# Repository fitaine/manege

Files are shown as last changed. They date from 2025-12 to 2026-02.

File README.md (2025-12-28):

# Manège 🎠
## A Simple 360° Photo Turntable for Documenting Your Work

<p align="center">
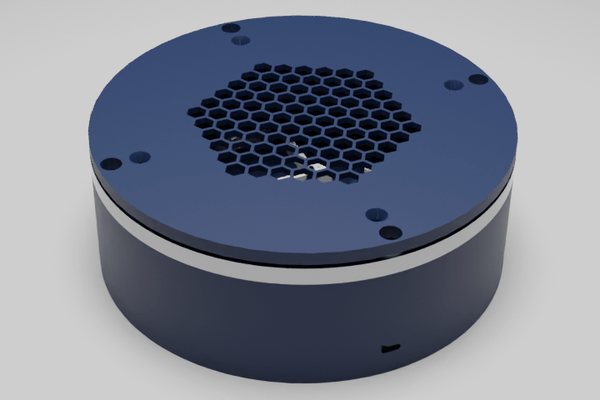
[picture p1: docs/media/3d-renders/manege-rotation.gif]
Manège Turntable Animation
  
</p>

I built this for my wife, who makes willow baskets. She needed a way to document everything she creates - to showcase her work to potential clients, remember past pieces, and build up a portfolio over time. Turns out photographing dozens of baskets gets tedious fast, so I made this automated turntable that uploads photos directly to her website.

It ain't much, but it's honest work. Maybe it'll be useful for your workshop too.

---

## What It Does

- Rotates objects on a turntable and takes photos automatically
- Uploads pictures to WordPress as you shoot (so your website stays updated)
- Has a simple web interface you can use from your phone
- Powers everything through a single Ethernet cable (PoE)
- Includes LED lighting control if you need consistent lighting

It's basically a lazy susan with a stepper motor, a Raspberry Pi with cameras, and some code to tie it together.

---

## Why I Built It This Way

### The Story
When you make things by hand - baskets, pottery, woodwork, whatever - you end up with a lot of items that need photographing. Setting up each shot, rotating the object, taking multiple angles... it's repetitive and takes time away from actual making.

My wife needed:
- A record of everything she's made (memory fades, photos don't)
- Images to show potential clients ("I can make something like this one")
- A way to keep her website gallery updated without the hassle

### The Solution
Instead of a fancy commercial product photography rig, I went with parts you can actually get:
- **Raspberry Pi 5** - Does the heavy lifting (cameras, web server, uploads)
- **ESP32** - Controls the turntable motor
- **PoE HAT** - Powers everything through the Ethernet cable (one less wire to worry about)
- **Lazy susan bearing** - The turntable base (8 inches, supports decent-sized objects)
- **Stepper motor** - Smooth, precise rotation

It's all open source hardware and software. Build it yourself, modify it, whatever works for you.

---

## What You Get

### Camera System
- Two Raspberry Pi cameras (one for preview, one for high-res shots)
- Manual controls for focus, exposure, white balance
- Live preview so you can see what you're shooting
- 360° sequences with however many photos you want

### Turntable
- 8-inch diameter (handles most hand-made objects)
- Precise rotation steps (can go as fine as 0.005625° per step)
- Controlled over WiFi from the web interface

### Web Interface
- Works on phones, tablets, computers - anything with a browser
- Simple controls: rotate, capture, adjust settings
- Live camera preview
- No app to install
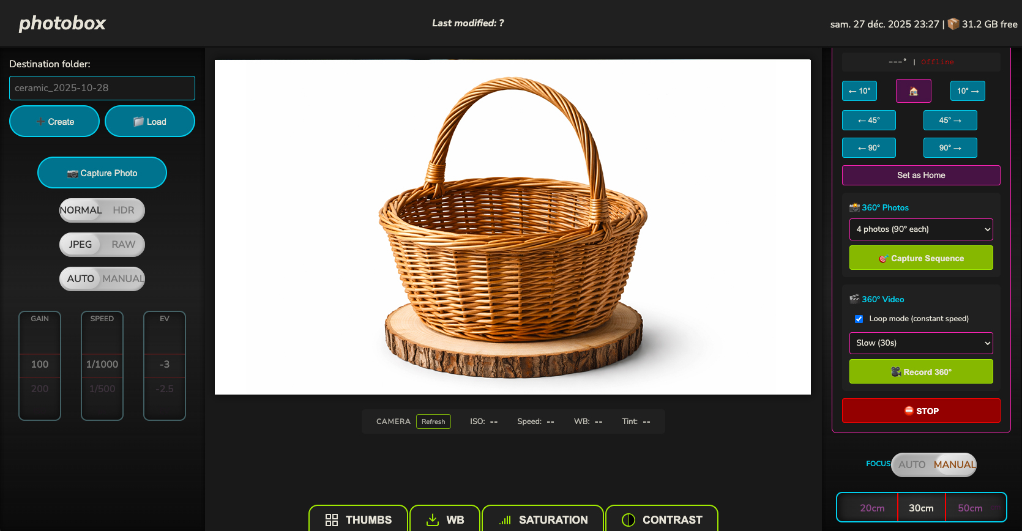
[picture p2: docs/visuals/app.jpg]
Manège Web Interface
<p align="center">    <br>  <em>The Manège web interface - live preview, camera controls, and automated 360° capture</em></p>

### WordPress Integration
- Photos upload automatically to your WordPress site
- Builds a gallery as you shoot
- Tag and organize as you go
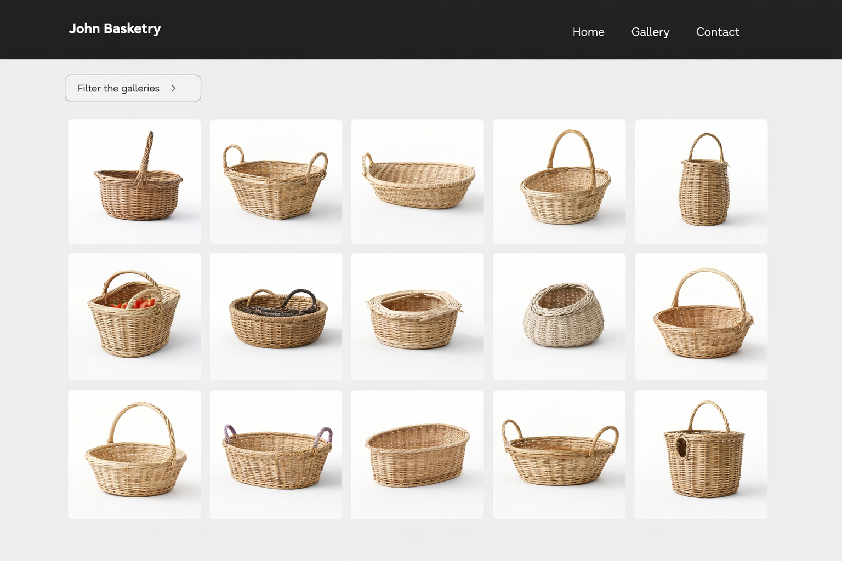
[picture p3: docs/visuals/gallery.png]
WordPress Gallery Grid
<p align="center">    <br>  <em>Example WordPress gallery showing organized product catalogue - clean grid layout for easy browsing</em></p>

### LED Control
- If you add LED strips for lighting, the system can control them
- Brightness adjustment via PWM
- All powered from the same PoE supply

---

## What You Need to Build One

### Core Parts
- Raspberry Pi 5 (8GB or 16GB)
- Raspberry Pi Camera Module 3
- Raspberry Pi HQ Camera
- PoE+ HAT for Raspberry Pi 5
- ESP32 dev board
- NEMA 17 stepper motor
- DRV8825 stepper driver
- 8-inch lazy susan bearing
- Power components (buck converters, etc.)

### Optional Additions
- LED light strips (12V COB strips work well)
- Enclosure (3D printable files included)
- MOSFET for LED control

**Full parts list with links: [BOM.md](BOM.md)**

The total cost is reasonable for what you get - cheaper than commercial photo turntables with fewer features.

---

## Getting Started

### Build the Hardware
Follow [ASSEMBLY_ORDER.md](ASSEMBLY_ORDER.md) for step-by-step instructions. The electrical wiring guide is in `hardware/electrical/wiring-guide.md`.

### Set Up the Software
```bash
cd manege
cp config.example.py config.py
nano config.py  # Add your WiFi and WordPress details
pip3 install -r requirements.txt
```

### Flash the ESP32
The turntable controller firmware is in `firmware/esp32_turntable/`. Upload it with Arduino IDE or PlatformIO.

### Start It Up
```bash
./scripts/start_webapp.sh
```

Then open `http://<raspberry-pi-ip>:5000` in your browser.

---

## How It Works

1. **Power On**: Plug in one PoE Ethernet cable. That's it - the Pi, cameras, LEDs, and turntable all power up.
2. **Take Photos**: Use the web interface to position your object, adjust camera settings, and capture.
3. **Auto-Upload**: Photos go straight to your WordPress media library and gallery.
4. **Keep Going**: Document your next piece. The system's ready whenever you are.

It's designed to be something you can use daily without thinking about it.

---

## Real Use Case: Willow Baskets

My wife makes traditional willow baskets. Each one is unique - different sizes, shapes, weaving patterns. Over a year, that's 50-100+ baskets.

Before Manège:
- Set up phone or camera on a tripod
- Manually rotate basket
- Take 8-12 photos per basket
- Transfer photos to computer
- Resize, rename, upload to website
- Repeat for next basket

With Manège:
- Place basket on turntable
- Press "Capture 360°"
- Watch it rotate and shoot automatically
- Photos appear in website gallery
- Done

The time savings add up fast. More importantly, she actually uses it - which means her website stays updated and potential clients can see what she's capable of making.

---

## Can You Use This?

If you make physical things and need photos of them, probably yes:
- Pottery, ceramics
- Woodworking, furniture
- Metalwork, jewelry
- Leather goods
- Textiles, baskets
- Scale models, miniatures
- Product prototypes

If you're just getting started and don't have many items yet, you might not need the automation. But if you're making dozens or hundreds of pieces a year, this saves real time.

---

## Documentation

- [Bill of Materials](BOM.md) - Parts list with supplier links
- [Assembly Guide](ASSEMBLY_ORDER.md) - How to build it
- [Wiring Guide](hardware/electrical/wiring-guide.md) - Electrical connections
- [Camera Setup](app/CAMERA_SETUP.md) - Configuring the Raspberry Pi cameras
- [Git Guide](GIT_QUICK_GUIDE.md) - How to contribute

---

## Contributing

This is an open project. If you build one and make improvements, share them:
- Better enclosure designs
- Code improvements
- Documentation fixes
- Ideas for features

[GitHub Issues](https://github.com/fitaine/manege/issues) is the place for bug reports and feature requests.

---

## License

- **Software**: MIT License - Use it however you want
- **Hardware**: CERN-OHL-P-2.0 - Open source hardware

Build it, sell products photographed with it, modify it for your needs. That's what open source is for.

---

## Credits

This project started with [twirly](https://github.com/veebch/twirly) by veebch - an elegant ESP32-based turntable. I added the Raspberry Pi cameras, PoE power system, LED control, WordPress integration, and web interface to make it work for documenting craft work at scale.

Thanks to veebch for the foundation and for open-sourcing their design.

---

## Support

Built in the Jura mountains of France, one piece at a time.

- **Website**: [tiphainebuccino.com](https://tiphainebuccino.com)
- **Issues**: [GitHub Issues](https://github.com/fitaine/manege/issues)

---

*Made for makers who'd rather spend time making things than photographing them.*

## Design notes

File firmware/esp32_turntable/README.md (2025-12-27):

# ESP32 Turntable Firmware

ESP32-based stepper motor controller for precision turntable rotation.

## Origins

The turntable control concept is inspired by [twirly](https://github.com/veebch/twirly) by veebch.

Manège extends this with:
- Enhanced precision (1/32 microstepping, 64,000 steps/360°)
- Multiple speed profiles for photography modes
- Loop-ready video mode
- Integration with Raspberry Pi camera

## Features

- Precision: 0.005625° per step (64,000 steps/360°)
- Microstepping: 1/32 for smooth motion
- HTTP API for WiFi control
- Multiple speed profiles (SLOW, MEDIUM, FAST, VIDEO)

## Configuration

1. Copy config.example.h to config.h
2. Edit with your WiFi credentials
3. Upload to ESP32 via Arduino IDE

## HTTP API Endpoints

- GET /status - Current position and state
- POST /left?degrees=N - Rotate left
- POST /right?degrees=N - Rotate right
- POST /home - Return to home position
- POST /photo360?count=N - Photo sequence mode
- POST /video360?duration=N - Video recording mode

## Hardware

- ESP32 DevKit
- NEMA 17 stepper motor
- DRV8825 driver
- 10:1 gear ratio

See hardware/ directory for complete documentation.

## Acknowledgments

Inspired by [twirly](https://github.com/veebch/twirly) by veebch.

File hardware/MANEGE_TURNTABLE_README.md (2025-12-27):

# Manège Turntable Project - Complete System Documentation

**Last Updated: November 28, 2025**
**Status: ✅ FULLY OPERATIONAL - Advanced Features Implemented**

---

## Table of Contents
1. [Overview](#overview)
2. [Current System Status](#current-system-status)
3. [What We've Achieved](#what-weve-achieved)
4. [System Architecture](#system-architecture)
5. [Features](#features)
6. [Hardware Configuration](#hardware-configuration)
7. [Software Components](#software-components)
8. [UI Layout](#ui-layout)
9. [Next Steps & TODO](#next-steps--todo)
10. [File Locations](#file-locations)
11. [Known Issues](#known-issues)

---

## Overview

Your manege is a complete automated photography system for capturing basketry and craft objects with:
- **Raspberry Pi Camera Module V3** (NoIR - No Infrared filter)
- **ESP32-controlled motorized turntable** with DRV8825 stepper driver
- **Web-based interface** for full remote control
- **Flask backend** (Python) serving camera and turntable APIs
- **Advanced camera controls**: Manual focus, exposure, WB, saturation, contrast
- **360° automation**: Photo sequences and video recording with loop mode

---

## Current System Status

### ✅ Working Features
- Live camera preview (MJPEG stream)
- Manual camera controls (focus, ISO, shutter, WB, saturation, contrast)
- HDR photo capture with EV compensation
- 360° photo sequences (4, 8, 12, 18 photos)
- 360° video recording with loop mode (constant-speed, loopable videos)
- Turntable manual control (left/right, home, set home)
- Emergency stop functionality
- Photo thumbnails with subfolder support
- Bottom panel UI (thumbnails, WB, saturation, contrast) - collapsed by default
- Focus: Horizontal carousel, manual mode by default (30cm)

### ⚠️ Needs Attention
- **ESP32 firmware upload required** for latest loop mode features
- Some UI elements may need final testing after recent changes

### 🔧 Configuration Details
- **Camera**: Raspberry Pi Camera Module V3 NoIR
- **Resolution**: 1920×1080 for video, configurable for photos
- **Network**:
  - Flask app: <PI_IP_ADDRESS>:5000
  - ESP32 turntable: <ESP32_IP_ADDRESS> (update if needed)
- **Photo storage**: `/home/yourusername/Pictures/` with date-organized folders

---

## What We've Achieved

### Session 1 (Nov 27, 2025) - Initial Integration
✅ ESP32 firmware created with HTTP API
✅ Flask backend turntable endpoints
✅ Web UI integrated into right panel
✅ Manual rotation controls working
✅ 360° photo sequences functional
✅ 360° video recording implemented

### Session 2 (Nov 28, 2025) - Advanced Features & Refinements

#### Camera & Capture Improvements
✅ Fixed camera blocking issues (pkill rpicam-vid before sequences)
✅ Added overlay messages during 360° capture/video
✅ Removed confirmation popups for smoother workflow
✅ Manual focus/exposure now applied in sequences
✅ Fixed EV settings conflict with HDR mode
✅ Enhanced emergency stop (kills processes, resets UI, restarts feed)
✅ Updated photo count options (4, 8, 12, 18 photos - removed 24+)
✅ Fixed thumbnails to show photos from sequence subfolders

#### ESP32 Firmware Enhancements
✅ Implemented 1/32 microstepping for smoother motion
✅ Gentle accelerations (300-500 steps/sec²) for basketry safety
✅ Return-to-home now uses shortest path (CW vs CCW)
✅ Dynamic speed calculation based on duration
✅ Proportional acceleration (reaches full speed in 10% of duration)
✅ **Loop mode implementation**:
  - Pre-positions backwards 10% (36°)
  - Accelerates through starting position to reach cruise speed
  - Records only constant-speed portion (80% of duration)
  - Decelerates after recording
  - Returns to exact starting position

#### Video Recording Features
✅ Loop mode checkbox (enabled by default)
✅ Speed presets: Fast (10s), Medium (20s), Slow (30s), Very Slow (45s), Ultra Slow (60s)
✅ Loop mode produces seamless, loopable videos
✅ Full rotation mode option (records acceleration/deceleration)
✅ Turntable returns to home position after loop mode video

#### UI Improvements
✅ Focus carousel made horizontal (saves ~130px vertical space)
✅ Focus carousel height reduced to 50px
✅ "FOCUS" label moved above auto/manual toggle
✅ Focus defaults to Manual mode with 30cm setting
✅ Focus carousel scrolls to 30cm position on load
✅ Bottom panel (thumbnails/WB/saturation/contrast) collapsed by default
✅ Removed redundant video controls

---

## System Architecture

```
┌─────────────────────────────────────────────────┐
│  Web Browser (Client)                           │
│  - HTML/CSS/JavaScript UI                       │
│  - Displays live camera feed                    │
│  - Controls camera & turntable                  │
└──────────────────┬──────────────────────────────┘
                   │ HTTP
                   ↓
┌─────────────────────────────────────────────────┐
│  Raspberry Pi (<PI_IP_ADDRESS>:5000)                │
│  ┌───────────────────────────────────────────┐  │
│  │ Flask App (Python)                        │  │
│  │ - Serves web UI                           │  │
│  │ - Controls camera (rpicam-vid/still)      │  │
│  │ - Proxies turntable commands              │  │
│  │ - Manages photo storage                   │  │
│  └───────────────────┬───────────────────────┘  │
│                      │                           │
│  ┌───────────────────┴───────────────────────┐  │
│  │ Camera Module V3 NoIR                     │  │
│  │ - Live preview stream                     │  │
│  │ - Photo capture (JPEG/RAW/DNG)            │  │
│  │ - Video recording (H264→MP4)              │  │
│  └───────────────────────────────────────────┘  │
└──────────────────┬──────────────────────────────┘
                   │ HTTP
                   ↓
┌─────────────────────────────────────────────────┐
│  ESP32 (<ESP32_IP_ADDRESS>)                           │
│  ┌───────────────────────────────────────────┐  │
│  │ HTTP Server (C++)                         │  │
│  │ - AccelStepper control                    │  │
│  │ - Position tracking                       │  │
│  │ - Loop mode logic                         │  │
│  └───────────────────┬───────────────────────┘  │
│                      │                           │
│  ┌───────────────────┴───────────────────────┐  │
│  │ DRV8825 Stepper Driver                    │  │
│  │ - 1/32 microstepping                      │  │
│  │ - NEMA stepper motor control              │  │
│  │ - 6400 steps/revolution                   │  │
│  └───────────────────┬───────────────────────┘  │
│                      │                           │
│  ┌───────────────────┴───────────────────────┐  │
│  │ NEMA Stepper Motor                        │  │
│  │ - Turntable rotation                      │  │
│  │ - 200 steps/rev (×32 microstepping)       │  │
│  └───────────────────────────────────────────┘  │
└─────────────────────────────────────────────────┘
```

---

## Features

### Camera Controls

#### Focus
- **Auto/Manual toggle**
- **Manual settings**: Infinity, 2m, 1m, 60cm, **30cm (default)**, 20cm, 15cm, 10cm
- **Horizontal carousel** interface (50px height)
- Position saved and applied to all captures

#### Exposure
- **Auto/Manual modes**
- **Manual controls**:
  - ISO: 100-800
  - Shutter: 1/8000 to 1 second
  - EV Compensation: -2 to +2 (HDR mode only)
- Settings preserved across sequences

#### White Balance
- **Presets**: Auto, Daylight, Cloudy, Shade, Tungsten, Fluorescent, Flash, Custom
- **Custom RGB tuning**: Fine-tune red/blue gains
- Applied to all photos and videos

#### Image Adjustments
- **Saturation**: -100 to +100
- **Contrast**: -100 to +100
- Real-time preview on live feed

### Photo Capture

#### Single Photo
- JPEG, RAW (DNG), or Both formats
- HDR mode with 3-bracket exposure
- Current settings applied (focus, WB, etc.)

#### 360° Photo Sequence
- **Photo counts**: 4, 8, 12, or 18 photos
- **Default**: 4 photos (90° spacing)
- Auto-rotation between shots
- Saved to timestamped subfolder (`360seq_YYYYMMDD_HHMMSS/`)
- Returns to home position when complete
- Thumbnails show in bottom panel

### Video Recording

#### 360° Video with Loop Mode
**Loop Mode (default, checkbox enabled):**
- Pre-positions backwards 36° before starting
- Accelerates to cruise speed while returning to start position
- Records only constant-speed rotation (no acceleration in video)
- Creates seamless, loopable videos perfect for web
- Returns to starting position after recording

**Speed Presets:**
- Fast (10s): ~8s of usable footage
- Medium (20s): ~16s of usable footage
- Slow (30s): ~24s of usable footage
- Very Slow (45s): ~36s of usable footage
- Ultra Slow (60s): ~48s of usable footage

**Full Rotation Mode (checkbox unchecked):**
- Records entire rotation including acceleration/deceleration
- Good for documentary-style captures

**Output**: MP4 format (H264 encoding, 1920×1080, 30fps)

### Turntable Controls

#### Manual Control
- **Left/Right**: Rotate in 10°, 45°, or 90° increments
- **Home**: Return to reference position (0°)
- **Set as Home**: Mark current position as starting point
- **Emergency Stop**: Immediate halt with full system reset

#### Automation
- 360° photo sequences (integrated with camera settings)
- 360° video recording with loop mode
- Smooth acceleration/deceleration for delicate objects
- Position tracking and return-to-home

### Safety Features
- Emergency stop kills all processes (camera + turntable)
- Gentle accelerations protect basketry and motor
- 1/32 microstepping eliminates vibration
- Shortest-path homing reduces wear
- Clear status indicators and overlay messages

---

## Hardware Configuration

### Raspberry Pi Camera
- **Model**: Raspberry Pi Camera Module V3 NoIR
- **Resolution**: 1920×1080 (video), higher for stills
- **Connection**: CSI ribbon cable (blue side facing USB ports)

### ESP32 Turntable
```
ESP32 Pins → DRV8825:
  STEP: GPIO 5
  DIR:  GPIO 2
  SLP:  GPIO 18
  RST:  GPIO 23
  EN:   GPIO 15
  M0:   GPIO 4  (HIGH for 1/32 microstepping)
  M1:   GPIO 22 (HIGH for 1/32 microstepping)
  M2:   GPIO 19 (HIGH for 1/32 microstepping)

Network:
  WiFi SSID: YourWiFiName
  Password: YourWiFiPassword
  Static IP: <ESP32_IP_ADDRESS>

Motor Configuration:
  Steps per revolution: 200 (NEMA 17)
  Microstepping: 1/32
  Total steps: 6400 per revolution
```

### Speed & Acceleration Settings
```cpp
// Speeds (steps per second)
SPEED_SLOW = 800      // Photo capture (very smooth)
SPEED_MEDIUM = 1200   // General positioning
SPEED_FAST = 1600     // Return home
SPEED_VIDEO = 400     // Ultra slow for video

// Accelerations (steps per second²)
ACCEL_SLOW = 300      // Very gentle start/stop
ACCEL_MEDIUM = 400    // Gentle acceleration
ACCEL_FAST = 500      // Return home (still gentle)

// Video mode uses dynamic calculation:
// accel = speed / (duration × 0.1)
// Reaches full speed in 10% of rotation time
```

---

## Software Components

### Backend: Flask App (`/home/yourusername/Documents/app.py`)

**Key Functions:**
- `video_feed()` - MJPEG live stream
- `capture_photo()` - Single photo with settings
- `capture_360_sequence()` - Automated photo sequence
- `record_360_video()` - 360° video with loop mode
- `kill_camera_processes()` - Emergency camera reset
- Turntable proxy endpoints (status, left, right, home, etc.)

**Recent Changes:**
- Added loop mode support with pre-positioning
- Dynamic video duration calculation (80% of total for loop mode)
- Return-to-home after loop mode videos
- Subfolder scanning for thumbnails
- Fixed HDR/manual exposure conflicts

### Frontend: Web UI (`/home/yourusername/Documents/templates/index.html`)

**Structure:**
- **Left Panel**: Live preview, capture overlay, photo modal
- **Right Panel**: Camera controls, turntable controls
- **Bottom Panel**: Thumbnails, WB tuning, Saturation, Contrast (collapsed by default)

**Key JavaScript Functions:**
- `capture360Sequence()` - Photo sequence with overlay
- `record360Video()` - Video recording with countdown
- `emergencyStop()` - Full system abort
- `createCarousel()` - Dynamic control carousels
- `updateLiveFocus()`, `updateLiveExposure()` - Real-time settings

### Firmware: ESP32 (`/home/yourusername/Documents/scripts/esp32_turntable/esp32_turntable.ino`)

**HTTP Endpoints:**
- `/status` - Get position and state
- `/left`, `/right` - Manual rotation
- `/rotate_degrees` - Rotate by specific amount
- `/home` - Return to home (shortest path)
- `/set_home` - Set current as home position
- `/photo360` - Photo sequence mode
- `/video360` - Normal video mode
- `/video360_loop` - **New: Loop mode with pre-positioning**
- `/stop` - Emergency stop

**Key Functions:**
- `handleVideo360Loop()` - **New: Pre-position, accelerate, cruise rotation**
- `handleHome()` - Shortest path calculation
- `rotateByDegrees()` - Smooth rotation with accel/decel
- `runToTarget()` - Blocking movement execution

---

## UI Layout

### Right Panel (Top to Bottom)

1. **Photo Format** (JPEG/RAW/Both dropdown)
2. **Capture Photo** button
3. **HDR Mode** toggle + EV slider
4. **Exposure Control** (Auto/Manual toggle + ISO/Shutter carousels)
5. **360° Photo Sequence** (count selector + Capture button)
6. **Turntable Manual Controls** (Left/Right buttons, Home, Set Home)
7. **360° Video** (Loop mode checkbox + speed selector + Record button)
8. **Emergency Stop** button (red)
9. **Focus Control** ("FOCUS" title + Auto/Manual toggle + horizontal carousel)

### Bottom Panel (Tabs - Collapsed by Default)

- **Thumbnails**: Recent photos with subfolder support
- **White Balance**: Preset selector + custom RGB tuning
- **Saturation**: Slider (-100 to +100)
- **Contrast**: Slider (-100 to +100)

---

## Next Steps & TODO

### 🔴 Critical - Must Do
1. **Upload updated ESP32 firmware** to enable:
   - Loop mode pre-positioning
   - 1/32 microstepping
   - Shortest-path homing
   - Dynamic acceleration

2. **Test loop mode video** after firmware upload:
   - Verify pre-positioning works
   - Check if object returns to exact start position
   - Confirm video has constant speed (no acceleration visible)

### 🟡 Important - Should Do
3. **Calibrate turntable speeds** for your specific setup:
   - Test different video presets (10s, 20s, 30s)
   - Adjust if rotation too fast/slow for your objects
   - Fine-tune acceleration times if needed

4. **Document your workflow**:
   - Best settings for different basket types
   - Lighting setup notes
   - Object placement guidelines

5. **Backup configuration**:
   ```bash
   cp /home/yourusername/Documents/app.py /home/yourusername/Documents/app.py.backup
   cp /home/yourusername/Documents/scripts/esp32_turntable/esp32_turntable.ino /home/yourusername/Documents/scripts/esp32_turntable/esp32_turntable.ino.backup
   ```

### 🟢 Nice to Have - Future Enhancements
6. **Video post-processing**:
   - Auto-trim to exact 360° rotation
   - Color grading pipeline
   - Batch processing scripts

7. **Additional camera features**:
   - Bracketed focus stacking
   - Timelapse mode with rotation
   - Multi-row captures (vertical adjustment)

8. **UI improvements**:
   - Save/load preset configurations
   - Quick access to recent settings
   - Keyboard shortcuts

9. **Hardware upgrades**:
   - Limit switches for precision homing
   - Position encoder for closed-loop control
   - LED ring light integration
   - Vertical axis control for 3D scanning

10. **Export features**:
    - Photogrammetry mesh generation
    - Automatic background removal
    - 360° viewer web embed code

---

## File Locations

### Core Files
```
Flask Backend:
  /home/yourusername/Documents/app.py

Web UI:
  /home/yourusername/Documents/templates/index.html

ESP32 Firmware:
  /home/yourusername/Documents/scripts/esp32_turntable/esp32_turntable.ino

Photo Storage:
  /home/yourusername/Pictures/YYYY-MM-DD/
  /home/yourusername/Pictures/YYYY-MM-DD/360seq_YYYYMMDD_HHMMSS/

Current Folder Tracker:
  /home/yourusername/Pictures/current_folder.txt
```

### Documentation
```
Main README:
  /home/yourusername/Documents/MANEGE_TURNTABLE_README.md (this file)

Setup Guide:
  /home/yourusername/Documents/TURNTABLE_SETUP.md

TODO List:
  /home/yourusername/Documents/TODO.md (to be created)

Session Notes:
  See conversation history for detailed implementation notes
```

### Scripts
```
Flask Startup:
  /home/yourusername/Documents/scripts/start_webapp.sh
  /home/yourusername/Documents/scripts/run_manege.sh
```

---

## Known Issues

### Camera Feed Occasionally Disappears
**Symptom**: Live preview stops loading
**Cause**: rpicam-vid process dies or gets stuck
**Solution**: Emergency stop button kills and restarts camera processes
**Prevention**: Current implementation includes automatic cleanup before sequences

### Thumbnails Don't Update Immediately
**Symptom**: New photos don't appear in thumbnail panel right away
**Cause**: Thumbnail refresh was removed to prevent scope errors
**Workaround**: Click on thumbnail tab to manually refresh
**Future Fix**: Implement proper scoped refresh function

### Focus Carousel Position on Page Load
**Status**: ✅ FIXED - Now scrolls to 30cm on initialization
**Implementation**: Searches for `.selected` item and scrolls to it

### Loop Mode Timing
**Status**: ⚠️ NEEDS TESTING after firmware upload
**Note**: Pre-positioning and acceleration times are estimates
**Potential Issue**: Object might not be exactly at start position when recording begins
**Solution**: Fine-tune timing constants in app.py:
```python
accel_time = duration * 0.1  # Adjust if needed
preposition_time = 2.0       # Adjust if needed
```

---

## Troubleshooting Quick Reference

| Problem | Solution |
|---|---|
| Camera not detected | Check ribbon cable, run `vcgencmd get_camera` |
| Live feed not loading | Emergency Stop, wait 2s, refresh page |
| Turntable shows "Offline" | Check ESP32 power, WiFi, verify IP <ESP32_IP_ADDRESS> |
| Motor not moving | Verify wiring, check VMOT voltage, test with `/status` |
| Jerky rotation | Upload latest firmware with 1/32 microstepping |
| Photos not in thumbnails | Click thumbnails tab, check `/home/yourusername/Pictures/` |
| Video too fast/slow | Change speed preset or adjust firmware constants |
| Loop mode not working | Upload latest ESP32 firmware with `handleVideo360Loop()` |
| Object not at start after loop | Adjust `preposition_time` in app.py |

---

## Useful Commands

### Camera
```bash
# Check camera detection
vcgencmd get_camera

# List camera processes
ps aux | grep rpicam

# Kill all camera processes
sudo pkill -9 -f rpicam

# Test camera capture
rpicam-still -o test.jpg
```

### Flask App
```bash
# Check if Flask is running
pgrep -f "flask run"

# View Flask logs
tail -f /tmp/flask.log

# Restart Flask (if using systemd)
sudo systemctl restart manege
```

### ESP32
```bash
# Test ESP32 connectivity
curl http://<ESP32_IP_ADDRESS>/status

# Test rotation
curl -X POST http://<ESP32_IP_ADDRESS>/preset/45
```

### Photos
```bash
# List recent photos
ls -lth /home/yourusername/Pictures/2025-11-28/ | head

# Count photos in sequences
find /home/yourusername/Pictures/ -name "360seq_*" -type d | wc -l

# Check disk space
df -h /home/yourusername/Pictures/
```

---

## Credits & Licenses

**Project**: Custom manege for basketry documentation
**Hardware**: Raspberry Pi, ESP32, DRV8825, NEMA stepper, Camera Module V3
**Software Stack**: Flask, rpicam-apps, AccelStepper, ArduinoJson

**Libraries Used:**
- Flask (Pallets Projects) - BSD License
- AccelStepper (Mike McCauley) - GPL
- ArduinoJson (Benoit Blanchon) - MIT License
- rpicam-apps (Raspberry Pi Foundation) - BSD License

---

## Support & Maintenance

### Regular Maintenance
- Clean camera lens monthly
- Check motor temperature after long sequences
- Tighten wire connections if vibration occurs
- Keep firmware and app.py backed up
- Test emergency stop periodically

### Getting Help
- Review this document first
- Check TURNTABLE_SETUP.md for detailed guides
- Check conversation history for implementation details
- Test individual components in isolation

---

**Ready to capture professional 360° basketry photos and videos!** 📷🔄✨

**Next step**: Upload the updated ESP32 firmware to enable loop mode!

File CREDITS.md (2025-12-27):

# Credits & Attribution

## Original Inspiration

**Manège** began as a development of the [twirly](https://github.com/veebch/twirly) project by [veebch](https://github.com/veebch).

### twirly - Original Project
- **Repository:** https://github.com/veebch/twirly
- **Author:** veebch
- **Concept:** ESP32-controlled turntable for product photography
- **License:** MIT License

### What We Borrowed from twirly
- ESP32 + stepper motor architecture
- Basic HTTP API concept for turntable control
- Inspiration for 360° rotation automation
- DRV8825 stepper driver approach

### What Manège Adds
Manège evolved twirly into a **complete photography solution** for artisans and craftspeople:

**Camera System:**
- Raspberry Pi Camera Module V3 integration
- Live MJPEG preview stream
- Manual focus control with preset positions
- Manual exposure (ISO + shutter speed)
- White balance sampling and adjustment
- HDR capture mode (3-exposure bracketing)
- RAW + JPEG capture options

**Software:**
- Flask-based web interface
- 360° photo sequencing automation
- 360° video recording with loop mode
- Photo management and storage
- Real-time camera preview with controls

**Hardware Enhancements:**
- Higher precision: 64,000 steps/360° (vs standard resolution)
- 1/32 microstepping for smooth motion
- Multiple speed profiles (photo, video, positioning)
- Network configuration system
- Professional wiring and power design

**Target Audience:**
- Professional and semi-professional photographers
- Artisans creating product catalogs
- Small businesses needing product photography
- Craftspeople (basketry, pottery, etc.)

## Development Philosophy

While inspired by twirly's elegant simplicity, Manège is a **separate development** aimed at a different use case:

- **twirly:** Minimalist turntable for basic 360° capture
- **Manège:** Complete photography system with professional features

This is not a fork in the technical sense, but rather a parallel development that took the core turntable concept and built a comprehensive solution around it.

## License Compatibility

Both projects use permissive open-source licenses:
- **twirly:** MIT License
- **Manège:** MIT License (software) + CERN-OHL-P-2.0 (hardware)

## Thank You

Special thanks to **veebch** for creating twirly and sharing it with the open-source community. Your project provided the perfect starting point for this development! 🙏

If you're looking for a **simple, minimalist turntable**, check out the original [twirly](https://github.com/veebch/twirly).

If you need a **complete photography system** with camera integration and advanced features, that's what Manège offers.

---

## Other Acknowledgments

### Software & Libraries
- **Flask** - Web framework (BSD License)
- **Pillow** - Image processing (HPND License)
- **libcamera** - Raspberry Pi camera interface
- **ArduinoJson** - JSON parsing for ESP32
- **AccelStepper** - Stepper motor control library

### Hardware
- **Raspberry Pi Foundation** - Pi and Camera Module
- **Espressif** - ESP32 platform
- **Community designs** - DRV8825 driver circuits

### Inspiration
- Artisan basketry photography workflows
- Professional product photography techniques
- Open-source hardware movement

---

**Manège** stands on the shoulders of giants. Thank you to everyone who contributes to open-source! 🎉

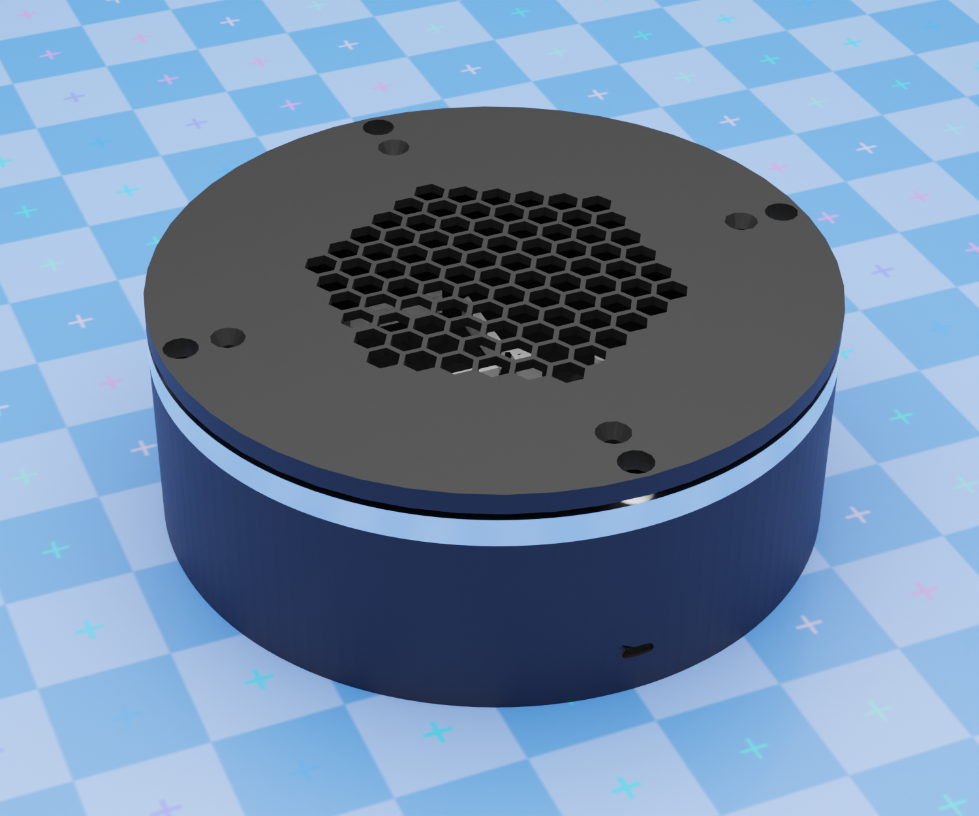
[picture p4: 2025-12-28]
docs/media/3d-renders/manege-turntable-render.png

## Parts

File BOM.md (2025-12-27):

# Bill of Materials (BOM)

Complete parts list for building Manège automated Manège.

**Source:** All parts available on AliExpress

---

## Core Electronics

| Component | Specs | Qty | Notes |
|---|---|-----|---|
| **Raspberry Pi 5** | 16GB RAM | 1 | Supports 2 cameras simultaneously |
| **Pi Camera HQ** | 12.3MP, C/CS mount | 1 | Main capture camera (high quality) |
| **Pi Camera Module V3** | 11.9MP, autofocus | 1 | Live preview stream |
| **Camera Cables** | 15-pin ribbon cables | 2 | One for each camera |
| **ESP32 DevKit** | WiFi enabled | 1 | Turntable controller |
| **NEMA 17 Stepper** | 200 steps/rev, 1.8° | 1 | Turntable motor |
| **DRV8825 Driver** | With heatsink | 1 | Stepper driver (1/32 microstepping) |

---

## Power System

| Component | Specs | Qty | Notes |
|---|---|-----|---|
| **XH-M291** | 12V Buck converter | 1 | 12V power distribution |
| **LM2596** | 5V Buck converter | 1 | 5V for Raspberry Pi |
| **12V Power Supply** | 2-3A minimum | 1 | Main power input |

---

## Mechanical

| Component | Specs | Qty | Notes |
|---|---|-----|---|
| **Lazy Susan** | 8 inch (200mm) | 1 | Rotating bearing platform |
| **Timing Belt & Pulleys** | 10:1 ratio (160T/16T) | 1 set | Gear reduction |
| **Mounting Hardware** | M3/M4 screws, brackets | 1 set | Assembly hardware |

---

## Wiring & Connectors

| Component | Qty | Notes |
|---|-----|---|
| **Jumper Wires** | 20-30 | Male-to-female, various colors |
| **Heat Shrink Tubing** | Assortment | Cable management |
| **Breadboard** (optional) | 1 | For prototyping/testing |

---

## Optional Upgrades

| Component | Purpose | Notes |
|---|---|---|
| **LED Strips** (8x) | Product lighting | 12V COB strips |
| **IRLZ44N MOSFET** | LED PWM control | Logic-level N-channel |
| **Resistors** | 1kΩ, 10kΩ | For MOSFET circuit |
| **Enclosure Materials** | Protective housing | 3D printed or fabricated |

---

## Camera Setup - Two Camera System

### Why Two Cameras?

**Camera HQ (Main Capture):**
- High quality photos (12.3MP)
- Interchangeable C/CS lenses
- Manual focus control
- RAW capture support
- Used for: Final 360° photos, product shots

**Camera Module V3 (Live Preview):**
- Fast autofocus
- Good for live streaming
- Lower latency
- Used for: Real-time preview, composition, framing

### Raspberry Pi 5 Requirement

Pi 5 has **dual camera connectors** - allows both cameras simultaneously:
- Camera HQ on CSI-0 (main photos)
- Module V3 on CSI-1 (live preview)

Earlier Pi models (4, 3, etc.) require camera multiplexer for dual cameras.

---

## Power Distribution

```
12V Power Supply
    │
    ├──> XH-M291 (12V distribution)
    │       ├──> NEMA 17 Stepper Motor
    │       ├──> LED Strips (optional)
    │       └──> LM2596 (12V → 5V)
    │               └──> Raspberry Pi 5
    │
    └──> ESP32 (via LM2596 or dedicated 5V)
```

---

## Critical Notes

⚠️ **Raspberry Pi 5 required** for dual camera setup (or use multiplexer with Pi 4)  
⚠️ **Camera HQ needs lens** - C or CS mount (6mm or 16mm recommended)  
⚠️ **DRV8825 needs heatsink** - Gets hot during operation  
⚠️ **Power calculations** - Ensure 12V supply can handle motor + LEDs  
⚠️ **Camera cables** - Check length needed for your enclosure

---

## Where to Buy

**Primary Source:** AliExpress
- Search terms: "Raspberry Pi 5", "NEMA 17", "DRV8825", "8 inch lazy susan"
- Typical shipping: 2-4 weeks
- Buy extras: jumper wires, heat shrink, screws

**Camera-Specific:**
- Pi Camera HQ + lens: Official distributors or AliExpress
- Ensure genuine Camera Module V3 (many clones exist)

**Power Components:**
- XH-M291: Search "XH-M291 buck converter"
- LM2596: Search "LM2596 DC-DC buck"
- 12V adapter: "12V 3A power supply"

---

## What You Might Already Have

Check your parts bin for:
- Jumper wires (Arduino kits)
- Breadboard
- USB cables
- Heat shrink tubing
- Basic hand tools
- Multimeter (for testing voltages)

---

**Last Updated:** December 2025

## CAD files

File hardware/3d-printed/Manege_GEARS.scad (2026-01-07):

// Manège Turntable Gears
  // Optimized for 146.8mm lazy susan inner diameter
  // Date: 2026-01-02

  include <gears.scad>;

  // === CONFIGURATION ===
  // PART SELECTOR: "ring", "pinion", or "both"
  part = "both";           // Change to "ring" or "pinion" to export individually

  module_size = 1.25;      // Module (tooth size)
  pinion_teeth = 22;       // Motor gear
  ring_teeth = 110;        // Lazy susan gear
  gear_width = 18;         // Can be 15-20mm
  pinion_bore = 5;         // Motor shaft diameter (adjust to your motor)
  rim_thickness = 3;       // Ring gear rim
  backlash = 0.2;          // Clearance between gears (mm)

  // === CALCULATED VALUES ===
  gear_ratio = ring_teeth / pinion_teeth;  // 5:1
  pinion_pitch_radius = (module_size * pinion_teeth) / 2;  // 13.75mm
  ring_pitch_radius = (module_size * ring_teeth) / 2;      // 68.75mm (internal)
  center_distance = ring_pitch_radius - pinion_pitch_radius - backlash;  // 54.8mm

  pinion_od = module_size * (pinion_teeth + 2);  // ~30mm
  ring_od = module_size * ring_teeth + (2 * rim_thickness);  // ~143.5mm

  echo("=== GEAR SPECIFICATIONS ===");
  echo(str("Rendering part: ", part));
  echo(str("Gear Ratio: ", gear_ratio, ":1"));
  echo(str("Pinion OD: ", pinion_od, "mm"));
  echo(str("Ring OD: ", ring_od, "mm"));
  echo(str("Center Distance: ", center_distance, "mm"));
  echo(str("Steps per revolution (1/32 microstepping): ", 200 * 32 * gear_ratio));

  // === RING GEAR (Lazy Susan - Centered) ===
  if (part == "ring" || part == "both") {
      herringbone_ring_gear(
          modul=module_size,
          tooth_number=ring_teeth,
          width=gear_width,
          rim_width=rim_thickness,
          pressure_angle=20,
          helix_angle=30
      );
  }

  // === PINION GEAR (Motor - Left Side, INSIDE ring) ===
  if (part == "pinion" || part == "both") {
      translate([-center_distance, 0, 0])
      herringbone_gear(
          modul=module_size,
          tooth_number=pinion_teeth,
          width=gear_width,
          bore=pinion_bore,
          pressure_angle=20,
          helix_angle=30,
          optimized=true
      );
  }

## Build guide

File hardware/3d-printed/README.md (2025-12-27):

# 3D Printed Parts for Manège

Custom 3D printed components for the Manège Manège system.

---

## Corner Brackets for LED Lightbox

**Design:** Corner brackets for building a photography lightbox frame  
**Published on Printables:** https://www.printables.com/model/1341411-corner-brackets-for-diy-photography-lightbox

### Purpose

These corner brackets are designed to build a cube-shaped LED lightbox that surrounds the Manège turntable system. The lightbox provides even, diffused lighting for professional product photography.

### Specifications

- **Wood Frame Size:** 20mm × 36mm (rectangular profile)
- **Bracket Type:** Corner connectors (8 pieces for a cube)
- **Material:** PLA or PETG recommended
- **Print Settings:** See Printables page for details

### How It Works

1. **Frame Construction:**
   - Cut 12 pieces of 20×36mm wood (4 per face × 3 faces)
   - Use 8 corner brackets to connect the frame into a cube
   - Manège turntable sits in the center

2. **Lighting Integration:**
   - Mount LED strips inside the frame
   - Cover with diffusion material (tracing paper, diffusion fabric)
   - Creates soft, even lighting from all sides

3. **Photography Benefits:**
   - 360° even illumination
   - Eliminates harsh shadows
   - Professional product photography quality
   - Compact and portable

### Assembly

Lightbox Frame Assembly

The brackets hold the wood frame at corners, creating a stable cube structure.

**Cube dimensions depend on wood length:**
- Example: 500mm wood pieces → 500mm cube interior
- Adjust size based on your product photography needs
- Larger for bigger objects, smaller for compact setup

### Bill of Materials

**For complete lightbox:**
- 8× Corner brackets (3D printed)
- 12× Wood pieces (20×36mm, length depends on desired size)
- LED strips (optional - for lighting)
- Diffusion material (tracing paper, fabric)
- Wood screws or glue (for assembly)

### Files Available

**On Printables:**
- STL files for corner brackets
- Printing instructions
- Assembly guide
- Community makes and remixes

**Download:** https://www.printables.com/model/1341411-corner-brackets-for-diy-photography-lightbox

### Print Settings Recommendation

- **Layer Height:** 0.2mm
- **Infill:** 20-30%
- **Supports:** Not required (designed to print without)
- **Material:** PLA (indoor use) or PETG (more durable)
- **Quantity:** Print 8 brackets for one cube

### Integration with Manège

**Setup:**
1. Build lightbox cube using brackets and wood
2. Place Manège turntable in center
3. Position camera(s) outside one open face
4. Add LED strips and diffusion for lighting
5. Rotate products while camera captures from fixed position

**Benefits:**
- Consistent lighting across 360° rotation
- Professional white/neutral background
- Eliminates external light variations
- Creates studio-quality product photos

### Design by NiphtiAe

This design is part of the Manège open-source Manège project.

**License:** Creative Commons or specified on Printables  
**Author:** NiphtiAe (Tiphaine Buccino)  
**Year:** 2024-2025

---

## Future 3D Printed Parts

Additional parts for Manège system (to be added):

### Planned Designs

- **Raspberry Pi Case** - Protective housing for Pi 5 with dual cameras
- **Camera Mounts** - Adjustable mounts for Camera HQ and Module V3
- **Motor Mount** - Bracket for NEMA 17 stepper motor
- **Cable Management** - Clips and guides for clean wiring
- **Turntable Platform** - Custom rotating platform design

### Contributing

Have you designed 3D printed parts for Manège? Share them!

1. Upload to Printables or Thingiverse
2. Open an issue on GitHub with the link
3. We will add it to this documentation

---

## Tips for 3D Printing Manège Parts

**General Guidelines:**

- **Material:** PLA for static parts, PETG for mechanical stress
- **Layer Height:** 0.2mm for most parts, 0.1mm for precision fits
- **Infill:** 20% for brackets, 50%+ for structural parts
- **Orientation:** Print for strength (layer lines perpendicular to stress)

**Design Considerations:**

- Account for wood tolerances (±0.5mm typical)
- Add clearance for easy assembly
- Consider vibration from motor (secure mounting)
- Plan for cable routing

---

**Questions or improvements?** Open an issue: https://github.com/fitaine/manege

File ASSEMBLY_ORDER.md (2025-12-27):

# Assembly Order

Step-by-step build sequence for Manège automated Manège.

**Estimated time:** 4-6 hours (spread over multiple sessions recommended)

---

## Prerequisites

Before starting, ensure you have:
- All parts from BOM.md
- Basic tools (screwdriver, wire strippers, multimeter)
- Soldering iron (optional, for permanent connections)
- Computer with SD card reader
- WiFi network for testing

---

## 1. Electronics Breadboard Test

**Goal:** Verify motor control works before permanent assembly

**Steps:**

- Connect DRV8825 to ESP32 (STEP→GPIO5, DIR→GPIO2, SLP→GPIO18)
- Connect DRV8825 to motor
- Add heatsink to DRV8825 (critical!)
- Upload basic ESP32 test code
- Verify motor rotates smoothly in both directions

**Success criteria:**
- Motor rotates in both directions
- DRV8825 warm but not burning hot
- No burning smell or sparks

---

## 2. Raspberry Pi Setup

**Goal:** Get both cameras working with Pi 5

**Steps:**

- Flash Raspberry Pi OS (64-bit, Bookworm or newer)
- Enable camera interface (sudo raspi-config)
- Connect Camera HQ to CSI-0, Module V3 to CSI-1
- Test camera detection (libcamera-hello --list-cameras)
- Install dependencies (libcamera-apps, Python packages)

**Success criteria:**
- Both cameras detected
- Can capture test photos from each camera
- SSH access working
- Python dependencies installed

---

## 3. 3D Printing

**Goal:** Protect the hardware from outside

**Print Steps:**
- Manège's base
- Top with honeycomb grid
- Gear
- Ring gear
- Raspi bottom case
- Raspi top case

## 4. Mechanical Assembly

**Goal:** Build stable rotating platform

**Steps:**

- Install NEMA 17 motor mount
- Install boards and converters
- Wire and Solder (Tricky part)
- Screw the ring gear and place the gear on the NEAM's shaft.

**Success criteria:**
- Turntable rotates smoothly by hand
- No mechanical binding or wobble
- Motor securely mounted
- Belt properly tensioned

---

## 5. Software Setup

**Goal:** Get Manège code running

**Steps:**

- Clone repository: git clone https://github.com/fitaine/manege.git
- Configure config.py (TURNTABLE_IP, FLASK_HOST, paths)
- Configure ESP32 config.h (WiFi credentials, static IP)
- Upload ESP32 firmware via Arduino IDE
- Start Flask app and test web interface

**Success criteria:**
- ESP32 connects to WiFi
- Flask web interface loads
- Can see camera preview
- Turntable controls respond

---

## 6. Final Integration

**Goal:** Complete system assembly and calibration

**Steps:**

- Mount both cameras at optimal positions
- Wire power system (12V → XH-M291 → motor/LM2596 → Pi)
- Organize wiring with cable ties and heat shrink
- Calibrate turntable home position
- Test full 360° photo sequence

**Success criteria:**
- All components powered correctly
- Cameras properly focused
- Full 360° sequence works
- Photos saved correctly
- System stable during operation

---

## Troubleshooting

**Motor doesn't move:**
- Check DRV8825 connections
- Verify 12V power supply
- Check ESP32 serial output
- Ensure SLP pin is HIGH

**Camera not detected:**
- Check cable connections (blue side to camera)
- Verify camera enabled in raspi-config
- Try different CSI port

**Web interface not loading:**
- Verify Pi IP address
- Check Flask is running
- Try accessing from Pi itself

**Turntable position drift:**
- Check belt tension
- Verify microstepping settings (1/32)
- Ensure motor not skipping steps

---

## Safety Notes

**Before each session:**
- Check 12V power supply polarity
- Verify all connections secure
- Ensure workspace is clear

**During operation:**
- Don't touch rotating parts
- Monitor for overheating
- Keep liquids away from electronics

---

## Next Steps

After successful assembly:

1. Calibration: Fine-tune camera focus and rotation speed
2. Documentation: Take photos of your build, share improvements
3. Start shooting: Test with real products!

---

**Enjoy your Manège Manège!**

For issues or questions, open an issue on GitHub: https://github.com/fitaine/manege

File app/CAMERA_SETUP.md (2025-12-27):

# Camera Setup Guide - Raspberry Pi Camera V3

IMPORTANT: This project uses libcamera, not the old picamera library\!

---

## Why libcamera?

### The Raspberry Pi Camera Mess (Short History)

**The Old Way (DEPRECATED):**
- Raspberry Pi Camera Module 1 & 2
- Python library: picamera
- Commands: raspistill, raspivid
- Problem: Does NOT work with Camera V3 or modern Raspberry Pi OS\!

**The New Way (CURRENT):**
- Raspberry Pi Camera Module 3
- Commands: libcamera-still, libcamera-vid, libcamera-hello
- Python: Use subprocess to call libcamera commands
- This is what Manège uses\!

### Why We Chose libcamera

✅ Works with Camera Module V3 (what we have)
✅ Supported by Raspberry Pi (actively maintained)
✅ Better manual controls (focus, exposure, white balance)
✅ RAW capture support
✅ Modern and future-proof

❌ Old picamera does NOT work with Camera V3
❌ Old raspistill/raspivid are deprecated

---

## What You Need

### Hardware
- Raspberry Pi 4 or 5
- Pi Camera Module V3 (critical\!)
- Camera cable (comes with camera)

### Software
- Raspberry Pi OS Bullseye or newer (64-bit recommended)
- libcamera-apps (usually pre-installed)

---

## Installation & Setup

### 1. Enable Camera Interface

sudo raspi-config

Navigate to: Interface Options → Camera → Enable
Reboot: sudo reboot

### 2. Check Camera Detection

After reboot:

libcamera-hello --list-cameras

Expected output:
Available cameras
0 : imx708 [4608x2592]

If you see this, camera is detected\! ✅

If you see "No cameras available":
- Check camera cable connection (blue side toward camera)
- Make sure camera interface is enabled in raspi-config
- Try: sudo reboot

### 3. Install libcamera-apps (if needed)

Usually pre-installed, but if not:

sudo apt update
sudo apt install libcamera-apps

### 4. Test Camera

Quick test (shows preview for 5 seconds):
libcamera-hello --timeout 5000

Take a test photo:
libcamera-still -o test.jpg

Record test video:
libcamera-vid -t 10000 -o test.h264

If these work, you are all set\! ✅

---

## How Manège Uses libcamera

### We DO NOT use picamera

This will NOT work:
from picamera import PiCamera  # Old library - does not work\!

### We DO use subprocess + libcamera commands

This is what we do in app.py:

import subprocess

# Start video stream
subprocess.Popen([
    "libcamera-vid",
    "--width", "1280",
    "--height", "720",
    "--codec", "mjpeg",
    "--listen",
    "-o", "tcp://0.0.0.0:8888"
])

# Capture photo
subprocess.run([
    "libcamera-still",
    "-o", "photo.jpg",
    "--width", "4608",
    "--height", "2592"
])

This is exactly how app/app.py works\!

---

## Common Issues & Solutions

### "No cameras available"

Check:
1. Camera cable connected properly (blue side to camera)
2. Camera interface enabled: sudo raspi-config
3. Camera detected: libcamera-hello --list-cameras
4. Try different camera port (Pi 5 has two ports)

### "Command not found: libcamera-still"

Fix:
sudo apt update
sudo apt install libcamera-apps

### "Timeout waiting for camera"

Causes:
- Camera already in use by another process
- Camera not connected
- Cable damaged

Fix:
sudo pkill libcamera
libcamera-hello

### "I want to use the old picamera library"

You cannot\! Camera Module V3 requires libcamera. Options:
1. Use libcamera (recommended - what Manège does)
2. Downgrade to Camera Module V2 + old OS (not recommended)

### "Stream not working in browser"

Check:
1. Camera stream is running: ps aux | grep libcamera
2. Port 8888 is accessible: curl http://localhost:8888
3. Firewall not blocking port

Restart stream:
cd /home/yourusername/manege
./scripts/stop_cam.sh
./scripts/start_cam.sh

---

## Camera Module V3 Specs

Our camera:
- Model: Raspberry Pi Camera Module V3
- Sensor: Sony IMX708
- Resolution: 11.9 megapixels (4608 x 2592)
- Focus: Autofocus + manual control (this is why we use it\!)
- Field of View: 66° diagonal

Special features we use:
- Manual focus control (for product photography)
- Manual exposure (ISO + shutter speed)
- RAW capture (DNG format)
- HDR mode

Note: We removed the NoIR filter for better color accuracy.

---

## Why This Matters for Manège

Product Photography Needs:
- Manual focus: Critical for consistent focus across 360° sequence
- Manual exposure: Prevents brightness changes between photos
- High resolution: 4608x2592 = high-quality product images
- RAW capture: Professional post-processing flexibility

libcamera gives us all of this\!

---

## Important Notes

1. Do NOT mix old and new:
   - Do NOT install picamera if using libcamera
   - Do NOT try to use raspistill/raspivid commands
   - Use ONLY libcamera commands

2. Python integration:
   - We use subprocess to call libcamera commands
   - This is the recommended way
   - No Python picamera library needed

3. Camera Module versions:
   - V1 & V2: Use old picamera library (deprecated)
   - V3: MUST use libcamera (that is us\!)

---

## The Camera Learning Curve

The camera situation was painful to figure out, but now it works reliably\!

Key lessons learned:
- Raspberry Pi changed camera systems (picamera → libcamera)
- Camera V3 ONLY works with libcamera
- Using subprocess is the right approach for Python
- Manual controls require specific libcamera flags

---

Official Documentation:
- libcamera: https://libcamera.org/
- Raspberry Pi Camera: https://www.raspberrypi.com/documentation/accessories/camera.html
- libcamera-apps: https://github.com/raspberrypi/libcamera-apps

---

Questions? Check the Raspberry Pi forums or open an issue on GitHub.

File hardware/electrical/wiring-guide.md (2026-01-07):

╔═══════════════════════════════════════════════════════════════════════╗
║           MANÈGE - QUICK WIRING REFERENCE                 ║
╚═══════════════════════════════════════════════════════════════════════╝

┌─────────────────────────────────────────────────────────────────────┐
│  ESP32 → DRV8825 CONNECTIONS (STEPPER CONTROL)                      │
└─────────────────────────────────────────────────────────────────────┘

    ESP32          Wire Color         DRV8825
  ─────────       (suggestion)       ─────────
   GPIO 5    ───────[ORANGE]───────→   STEP
   GPIO 2    ───────[YELLOW]───────→   DIR
   GPIO 18   ───────[GREEN]────────→   SLP
   GPIO 23   ───────[BLUE]─────────→   RST
   GPIO 15   ───────[PURPLE]───────→   EN (LOW = motor energized)
   GPIO 4    ───────[BROWN]────────→   M0  ───┐
   GPIO 22   ───────[GRAY]─────────→   M1  ───┼──→ HIGH (1/32 step)
   GPIO 19   ───────[WHITE]────────→   M2  ───┘
   GND       ───────[BLACK]────────→   GND

┌─────────────────────────────────────────────────────────────────────┐
│  ESP32 → LED CONTROL (PHOTOBOX)                                     │
└─────────────────────────────────────────────────────────────────────┘

    ESP32          Wire Color         MOSFET (IRLZ44N)
  ─────────       (suggestion)       ─────────────────
   GPIO 25   ───────[CYAN]──────────→   Gate (G)

   GND       ───────[BLACK]────────→   Source (S) ──→ Common GND

  LED POWER PATH (Low-Side Switching):
  ─────────────────────────────────────────────────────────
   XH-M291 12V OUT+ ──→ LED Strip (+)
                           ↓
                      LED Strip (-)
                           ↓
                    MOSFET Drain (D)
                           ↓
                    MOSFET Source (S) ──→ Common GND
                           ↑
                      Gate (G) ←── GPIO 25 (PWM signal)

  Note: GPIO 25 provides PWM (0-100% duty cycle) for brightness control
        MOSFET is placed AFTER the LED strip (low-side switching)

┌─────────────────────────────────────────────────────────────────────┐
│  PHOTOBOX POWER DISTRIBUTION (USB-C PD)                             │
└─────────────────────────────────────────────────────────────────────┘

  AC Outlet → USB-C PD Charger (100W, 20V@5A)
            → 5A E-Marked USB-C Cable
            → PD Trigger (20V output)
            → 20V Main Bus (distributes to 3 paths):

  Path 1: Buck 20V→5V → Diode → ESP32 VIN (~2W)
  Path 2: Stepper Driver (20V VMOT) → NEMA 17 (~20W)
  Path 3: XH-M291 Buck 20V→12V → LED Strips via MOSFET (~50W)

  Total Power Budget: ~72W / 100W available

  CRITICAL: All grounds must be common (use ground bus bar)!
  Wire Specs: 18 AWG for power, 22 AWG for signals

┌─────────────────────────────────────────────────────────────────────┐
│  DIODE PROTECTION (USB PROGRAMMING)                                 │
└─────────────────────────────────────────────────────────────────────┘

  Purpose: Allow ESP32 programming via USB while system runs

  Configuration:
  ┌──────────────────────────────────────────┐
  │  Buck 5V ──→|── Diode ──┬──→ ESP32 VIN  │
  │           (1N5819)      │                │
  │                         │                │
  │  USB 5V (internal) ─────┘                │
  │  (already connected                      │
  │   on ESP32 dev board)                    │
  └──────────────────────────────────────────┘

  Component: 1× 1N5819 Schottky Diode (1A rated)

  Installation:
  - Diode ANODE (stripe end = cathode) → Buck 5V output
  - Diode CATHODE → ESP32 VIN pin
  - Voltage drop: ~0.3V (ESP32 receives ~4.7V, which is fine)

  How it works:
  - When USB unplugged: Buck powers ESP32 through diode
  - When USB plugged in: USB powers ESP32, diode blocks backfeed to Buck
  - No board modification needed (simple one-diode solution)

┌─────────────────────────────────────────────────────────────────────┐
│  COMMON GROUND IMPLEMENTATION                                       │
└─────────────────────────────────────────────────────────────────────┘

  Use a ground rail/bus bar for clean wiring:

  USB-C PD Charger (-)
          │
          │ (one 18 AWG wire)
          ↓
     [GROUND RAIL/BUS BAR]
     ═════════════════════
      │  │  │  │  │  │  │
      │  │  │  │  │  │  └─→ LED Strip (-)
      │  │  │  │  │  └────→ MOSFET Source
      │  │  │  │  └───────→ XH-M291 IN(-) and OUT(-)
      │  │  │  └──────────→ DRV8825 GND
      │  │  └─────────────→ ESP32 GND
      │  └────────────────→ Buck 5V OUT(-)
      └───────────────────→ PD Trigger (-)

  Implementation Options:
  - Screw terminal block (recommended)
  - Ground bus bar
  - High-quality wire nuts

  Why: Cleaner wiring, easier troubleshooting, standard practice

┌─────────────────────────────────────────────────────────────────────┐
│  CAPACITOR PLACEMENT (CRITICAL!)                                    │
└─────────────────────────────────────────────────────────────────────┘

  Simple Rule: Connect capacitor (+) to device (+), and (-) to device (-)
               Place as CLOSE as possible to each device!

  TOTAL: 2 Required Capacitors + 1 Optional

  Capacitor 1: PD Trigger Output (20V Main Bus) - 100µF @ 50V
  ┌──────────────────────────────────────────┐
  │  PD ──┬─→ 20V Main Bus (+)               │
  │       │                                   │
  │     [100µF]  ← Place at PD trigger       │
  │     +    -     output terminals          │
  │       │                                   │
  │  GND ──┴─→ Ground bus bar                │
  │                                           │
  │  Purpose: Stabilizes 20V supply and      │
  │  handles load transients                 │
  └──────────────────────────────────────────┘

  Capacitor 2: Motor Power (20V VMOT) - 100µF @ 50V
  ┌──────────────────────────────────────────┐
  │  20V ──┬─→ DRV8825 VMOT pin              │
  │        │                                  │
  │     [100µF]  ← Place within 1-2cm        │
  │     +    -     of DRV8825 board          │
  │        │                                  │
  │  GND ──┴─→ DRV8825 GND pin               │
  │                                           │
  │  Connect capacitor (-) to DRV8825 GND    │
  │  pin directly, NOT to ground bus!        │
  └──────────────────────────────────────────┘

  LM2596 Buck Converter (5V) - ALREADY HAS CAPACITORS!
  ┌──────────────────────────────────────────┐
  │  NOTE: LM2596 board has built-in caps:  │
  │  • Input:  100µF @ 50V                  │
  │  • Output: 100µF @ 50V                  │
  │                                          │
  │  NO additional capacitors needed on     │
  │  the LM2596 board itself.               │
  └──────────────────────────────────────────┘

  XH-M291 Buck Converter (12V) - ALREADY HAS CAPACITORS!
  ┌──────────────────────────────────────────┐
  │  NOTE: XH-M291 board has built-in caps: │
  │  • C4 (input):  220µF @ 50V             │
  │  • C8 (output): 220µF @ 50V             │
  │                                          │
  │  NO additional capacitors needed on     │
  │  the XH-M291 board itself.              │
  └──────────────────────────────────────────┘

  Capacitor 3: At LED Strips - 220µF @ 25V [OPTIONAL]
  ┌──────────────────────────────────────────┐
  │  12V ──┬─→ LED Strip (+)                 │
  │        │                                  │
  │     [220µF]  25V rated                   │
  │     +    -   Place at LED connection     │
  │        │                                  │
  │  GND ──┴─→ LED Strip (-)                 │
  │                                           │
  │  ONLY add if:                            │
  │  • Experiencing PWM dimming flicker      │
  │  • Wires from XH-M291 to LEDs > 10cm    │
  └──────────────────────────────────────────┘

  BILL OF MATERIALS - Capacitors:
  ─────────────────────────────────────────────────────────
  □ 2× 100µF electrolytic @ 50V (PD Trigger output + DRV8825 VMOT)
  □ 1× 220µF electrolytic @ 25V [OPTIONAL - only if LED flicker]

  NOTE: LM2596 and XH-M291 buck converters have built-in capacitors!

  Voltage Rating Guide:
  - 20V circuits → use 50V rated (1.5× safety margin minimum)
  - 12V circuits → use 25V rated
  - 5V circuits  → use 25V rated (overkill but fine)

  Polarity: Longer leg = (+), Stripe/shorter leg = (-)

  IMPORTANT:
  - Place capacitors as close as possible to each device!
  - Connect capacitor legs to device pins, NOT directly to bus bar
  - This minimizes loop area for best noise filtering

┌─────────────────────────────────────────────────────────────────────┐
│  STEPPER MOTOR CONNECTIONS                                          │
└─────────────────────────────────────────────────────────────────────┘

  Stepper Motor (NEMA 17)            DRV8825
  ───────────────────────            ─────────
   Coil A - Wire 1 (Red)    ───────→   A1
   Coil A - Wire 2 (Green)  ───────→   A2

   Coil B - Wire 1 (Blue)   ───────→   B1
   Coil B - Wire 2 (Yellow) ───────→   B2

  IMPORTANT: NEMA 17 has NO separate ground wire!

  - Motor has only 4 coil wires
  - Motor ground reference comes through DRV8825 GND pin
  - Motor coils are isolated windings (no direct ground connection)
  - Optional: Ground metal motor case for EMI shielding (not required)

  Note: Wire colors may vary by manufacturer.
        Use multimeter to identify coil pairs (continuity test).

┌─────────────────────────────────────────────────────────────────────┐
│  VOLTAGE SETTINGS                                                   │
└─────────────────────────────────────────────────────────────────────┘

  Component              Voltage       Notes
  ─────────────────────────────────────────────────────────────
  ESP32                  5V            From Buck via diode (~4.7V at VIN)
  DRV8825 Logic (VDD)    5V            From Buck converter
  DRV8825 Motor (VMOT)   20V           Direct from PD Trigger
  NEMA 17 (typical)      12-20V        Check motor datasheet
  XH-M291 Input          20V           From PD Trigger
  XH-M291 Output         12V           Adjust to exactly 12.0V
  LED Strips             12V           COB strips, ~50W total

┌─────────────────────────────────────────────────────────────────────┐
│  NETWORK CONFIGURATION                                              │
└─────────────────────────────────────────────────────────────────────┘

  Device              IP Address         Port    Protocol
  ───────────────────────────────────────────────────────────
  Raspberry Pi        192.168.1.100      5000    HTTP (Flask)
  ESP32 Turntable     192.168.1.42       80      HTTP (WebServer)

  WiFi SSID:     YourWiFiName
  WiFi Password: YourWiFiPassword

┌─────────────────────────────────────────────────────────────────────┐
│  GPIO PIN SUMMARY                                                   │
└─────────────────────────────────────────────────────────────────────┘

  Stepper Control:
  ────────────────────────────────────────────────────────────
   GPIO 5   → STEP     GPIO 15  → EN (LOW = motor energized)
   GPIO 2   → DIR      GPIO 4   → M0
   GPIO 18  → SLP      GPIO 22  → M1
   GPIO 23  → RST      GPIO 19  → M2

  LED Control:
  ────────────────────────────────────────────────────────────
   GPIO 25  → MOSFET Gate (PWM for brightness, low-side switch)

  Available GPIOs for future use:
  ────────────────────────────────────────────────────────────
   GPIO 12, 13, 14, 16, 17, 21, 26, 27, 32, 33

┌─────────────────────────────────────────────────────────────────────┐
│  TESTING CHECKLIST                                                  │
└─────────────────────────────────────────────────────────────────────┘

  Turntable System:
  ─────────────────────────────────────────────────────────────
  □ 1. Power off everything
  □ 2. Install 100µF@50V cap at PD Trigger output (20V main bus)
  □ 3. Install 1N5819 diode between Buck 5V and ESP32 VIN
  □ 4. Install 100µF@50V cap on 20V VMOT (at DRV8825 pins)
  □ 5. Set up ground bus bar (screw terminal block)
  □ 6. Connect all grounds to ground bus bar
  □ 7. Connect ESP32 to DRV8825 (8 control signals)
  □ 8. Connect 20V power to DRV8825 VMOT
  □ 9. Connect 5V power to DRV8825 VDD
  □ 10. Connect stepper motor 4 wires to DRV8825 (A1, A2, B1, B2)
  □ 11. Set M0, M1, M2 to HIGH (1/32 microstepping)
  □ 12. Upload firmware to ESP32 (via USB)
  □ 13. Open Serial Monitor, verify WiFi connection
  □ 14. Test via browser: http://192.168.1.42/status
  □ 15. Test rotation: /rotate_degrees?degrees=45
  □ 16. Test Flask integration from Manège UI

  LED System:
  ─────────────────────────────────────────────────────────────
  □ 1. Connect XH-M291 input to 20V main bus
  □ 2. Adjust XH-M291 output to exactly 12.0V (use multimeter)
  □ 3. Connect GPIO 25 to MOSFET Gate
  □ 4. Connect 12V from XH-M291 to LED Strip (+)
  □ 5. Connect LED Strip (-) to MOSFET Drain
  □ 6. Connect MOSFET Source to ground bus bar
  □ 7. Test with 1 LED strip first
  □ 8. Test PWM control: /led?brightness=50
  □ 9. Add remaining LED strips gradually
  □ 10. Verify total current < 3A
  □ 11. If LED flicker occurs, add 220µF@25V cap at LED strips

┌─────────────────────────────────────────────────────────────────────┐
│  TROUBLESHOOTING - NO MOVEMENT                                      │
└─────────────────────────────────────────────────────────────────────┘

  Check:
  ✓ VMOT voltage present (use multimeter, should be 20V)
  ✓ VDD voltage present (should be 5V)
  ✓ EN pin is LOW (motor enabled, GPIO 15 = LOW)
  ✓ Ground bus bar properly connected
  ✓ Motor coils connected correctly (all 4 wires, no 5th ground wire)
  ✓ ESP32 sending signals (check Serial Monitor)
  ✓ WiFi connected (ESP32 shows IP address)
  ✓ Capacitors installed correctly (polarity!)

┌─────────────────────────────────────────────────────────────────────┐
│  TROUBLESHOOTING - ERRATIC MOVEMENT                                 │
└─────────────────────────────────────────────────────────────────────┘

  Fix:
  ✓ Check capacitor placement (within 1-2cm of DRV8825)
  ✓ Verify capacitor polarity (+ to +, - to -)
  ✓ Check capacitor connections (to device pins, not bus)
  ✓ Check wire connections (loose wires)
  ✓ Verify power supply current rating (≥2A)
  ✓ Reduce speed in firmware (SPEED_FAST = 500)
  ✓ Check motor current limit pot on DRV8825

┌─────────────────────────────────────────────────────────────────────┐
│  TROUBLESHOOTING - LEDs NOT WORKING / FLICKERING                    │
└─────────────────────────────────────────────────────────────────────┘

  Check:
  ✓ XH-M291 output is 12.0V (measure with multimeter)
  ✓ XH-M291 onboard capacitors present (C4 and C8, 220µF each)
  ✓ MOSFET is logic-level (IRLZ44N works with 3.3V)
  ✓ GPIO 25 PWM signal present (use /led?brightness=255)
  ✓ LED wiring: 12V → LED(+), LED(-) → MOSFET Drain
  ✓ MOSFET Source connected to ground bus bar
  ✓ Total current < 3A (XH-M291 max)
  ✓ All grounds are common (check ground bus)
  ✓ Check LED strip connections (loose wires)

  LED Flicker Causes:
  ✓ Long wires from XH-M291 to LED strips (>10cm)
  ✓ Add 220µF @ 25V cap at LED strip connection if flickering
  ✓ Wrong MOSFET wiring (LED strip must come BEFORE MOSFET)
  ✓ PWM frequency too low (firmware uses 5kHz, should be OK)
  ✓ Loose connections or bad solder joints

┌─────────────────────────────────────────────────────────────────────┐
│  CURRENT LIMIT ADJUSTMENT (DRV8825)                                 │
└─────────────────────────────────────────────────────────────────────┘

  Most NEMA 17: ~1.2A per phase

  DRV8825 formula: VREF = Current_Limit × 0.8

  For 1.2A motor: VREF = 1.2 × 0.8 = 0.96V

  Steps:
  1. Power off system
  2. Set multimeter to DC voltage
  3. Connect black probe to GND
  4. Connect red probe to potentiometer center (metal part)
  5. Power on (without motor connected)
  6. Measure voltage (should read ~0.96V for 1.2A)
  7. Adjust potentiometer with small screwdriver
     - Clockwise = increase current
     - Counter-clockwise = decrease current
  8. Power off, connect motor, test

  Safety: Start with lower current (0.8A = 0.64V) and increase if needed

═══════════════════════════════════════════════════════════════════════

  References:
  - Twirly project: github.com/veebch/twirly
  - MANÈGE project: github.com/fitaine/manege

  For detailed instructions, see:
  /home/florine/manege/hardware/MANEGE_TURNTABLE_README.md

═══════════════════════════════════════════════════════════════════════

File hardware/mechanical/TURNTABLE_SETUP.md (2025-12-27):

# Manège Turntable Setup Guide

## Hardware Components
- ESP32 development board
- DRV8825 stepper motor driver
- NEMA 17 stepper motor (200 steps/rev recommended)
- Step-down converter (to match your motor's voltage)
- 2x Capacitors (100µF and 10µF)
- Jumper wires
- Power supply

## Wiring Diagram

### ESP32 to DRV8825 Connections
```
ESP32 Pin    →    DRV8825 Pin    Purpose
──────────────────────────────────────────
GPIO 5       →    STEP           Step signal
GPIO 2       →    DIR            Direction control
GPIO 18      →    SLP            Sleep mode control
GPIO 23      →    RST            Reset
GPIO 4       →    M0             Microstepping (set to GND for full step)
GPIO 22      →    M1             Microstepping (set to GND for full step)
GPIO 19      →    M2             Microstepping (set to GND for full step)
GPIO 15      →    EN             Enable (active LOW)
GND          →    GND            Common ground
```

### DRV8825 to Motor & Power
```
DRV8825 Pin       Connection
──────────────────────────────────────────
VMOT             → Step-down converter (+) output
GND              → Step-down converter (-) output & ESP32 GND
A1, A2           → Motor coil A
B1, B2           → Motor coil B
M0, M1, M2       → GND (for full step mode)
```

### Power Supply
```
Power Supply (+) → Step-down converter input (+)
Power Supply (-) → Step-down converter input (-) & Common GND

Step-down output: Adjust to match your motor voltage
  - NEMA 17 typical: 12V
  - Check your motor datasheet
```

### Capacitor Placement
```
100µF capacitor: Between VMOT and GND (close to DRV8825)
10µF capacitor:  Between VMOT and GND (additional filtering)
```

## Software Setup

### 1. Install Arduino IDE Libraries
Open Arduino IDE and install these libraries via Library Manager:
- WiFi (built-in)
- WebServer (built-in)
- AccelStepper (by Mike McCauley)
- ArduinoJson (by Benoit Blanchon)

### 2. Configure WiFi
Edit the ESP32 firmware (`esp32_turntable.ino`):
```cpp
const char* ssid = "YOUR_WIFI_SSID";        // Change to your WiFi name
const char* password = "YOUR_WIFI_PASSWORD"; // Change to your WiFi password
```

The ESP32 will use static IP: **192.168.1.42**

If you need to change the IP, edit these lines:
```cpp
IPAddress local_IP(192, 168, 1, 42);    // Change last number
IPAddress gateway(192, 168, 1, 1);      // Your router IP
IPAddress subnet(255, 255, 255, 0);
```

### 3. Upload Firmware
1. Connect ESP32 to your computer via USB
2. Open `esp32_turntable.ino` in Arduino IDE
3. Select board: **ESP32 Dev Module** (Tools → Board)
4. Select correct COM port (Tools → Port)
5. Click Upload

### 4. Verify Connection
After upload, open Serial Monitor (115200 baud):
```
Connecting to WiFi...
WiFi connected!
IP: 192.168.1.42
HTTP server started
Manège Turntable Ready!
```

### 5. Test ESP32 API
Open browser and visit: `http://192.168.1.42`

You should see the API documentation page.

Test rotation:
```
http://192.168.1.42/preset/45   (rotate 45°)
http://192.168.1.42/status      (check position)
```

### 6. Install Python Dependencies
On your Raspberry Pi:
```bash
pip3 install requests
```

### 7. Update Flask App
The turntable features are already integrated in `/home/yourusername/Documents/app.py`

Verify the ESP32 IP address matches:
```python
TURNTABLE_IP = "192.168.1.42"
TURNTABLE_ENABLED = True
```

### 8. Add UI to Web Interface
The turntable UI snippet is in `/home/yourusername/Documents/turntable_ui_snippet.html`

To add it to your Manège interface:
1. Open `/home/yourusername/Documents/templates/index.html`
2. Find a suitable location (e.g., after the camera settings section)
3. Copy the HTML section from `turntable_ui_snippet.html`
4. Copy the JavaScript section into your existing `<script>` block

## Features

### Manual Control
- **Left/Right buttons**: Rotate by 10°, 45°, or 90°
- **Home button**: Return to home position (0°)
- **Set as Home**: Define current position as 0°

### 360° Photo Sequence
Automatically captures multiple photos while rotating:
- Choose 12, 18, 24, 36, or 72 photos
- Photos saved in timestamped subfolder
- Returns to home position after completion

### 360° Video Recording
Records video while rotating smoothly:
- Choose duration: 10-60 seconds
- Camera and turntable synchronized
- Smooth rotation for professional results

### Emergency Stop
Immediately stops all turntable movement.

## API Endpoints

### Turntable Control (Flask → ESP32)
```
GET  /turntable/status              - Get position and state
POST /turntable/left?degrees=N      - Rotate left (CCW)
POST /turntable/right?degrees=N     - Rotate right (CW)
POST /turntable/goto?position=N     - Go to absolute position
POST /turntable/home                - Return to home (0°)
POST /turntable/set_home            - Set current as home
POST /turntable/stop                - Emergency stop
```

### Advanced Features
```
POST /capture_360_sequence
     Parameters: photo_count, format

POST /record_360_video
     Parameters: duration
```

## Troubleshooting

### ESP32 not connecting to WiFi
1. Check WiFi credentials in firmware
2. Verify WiFi network is 2.4GHz (ESP32 doesn't support 5GHz)
3. Check Serial Monitor for error messages

### Motor not moving
1. Verify all wiring connections
2. Check if EN pin is LOW (motor enabled)
3. Measure voltage at VMOT (should match motor voltage)
4. Test with `/preset/45` endpoint

### Motor moving erratically
1. Check capacitor placement (close to DRV8825)
2. Verify power supply current rating (≥1A recommended)
3. Adjust AccelStepper speed/acceleration values

### Motor too slow/fast
Edit firmware speed settings:
```cpp
const int SPEED_SLOW = 300;      // Lower = slower
const int SPEED_MEDIUM = 600;
const int SPEED_FAST = 1000;
```

### Turntable offline in web interface
1. Verify ESP32 is powered and connected to WiFi
2. Check IP address: `http://192.168.1.42`
3. Verify TURNTABLE_IP in Flask app matches ESP32 IP
4. Check both devices are on same network

### Photos not synchronized with rotation
1. Increase settle time in `capture_360_sequence` function
2. Reduce rotation speed (SPEED_SLOW constant)
3. Check for vibrations in mechanical setup

## Mechanical Assembly Tips

### Turntable Platform
- Use a lazy susan bearing for smooth rotation
- Mount motor underneath platform
- Use timing belt or direct coupling to stepper shaft

### Camera Positioning
- Keep camera stationary, rotate object
- Ensure camera is centered and perpendicular to turntable
- Use diffused lighting to minimize shadows

### Object Placement
- Center object on turntable
- Mark home position on platform for repeatability
- Keep objects within weight limit of motor/platform

## Calibration

### Find Home Position
1. Manually rotate turntable to desired starting position
2. Click "Set as Home" button in UI
3. ESP32 will remember this as 0°

### Test Accuracy
1. Click "Home" button
2. Click "Preset/360" to do full rotation
3. Should return to exact same position
4. If not, check:
   - STEPS_PER_REV setting (200 for most NEMA 17)
   - Mechanical slippage (belt tension, coupling)

## Safety Notes

- **Emergency Stop**: Always accessible in UI
- **Power**: Never connect/disconnect motor while powered
- **Voltage**: Double-check motor voltage before powering
- **Current**: DRV8825 current limit should be set for your motor
- **Heat**: DRV8825 may need heatsink for continuous operation

## Next Steps / Enhancements

- Add position encoder for closed-loop control
- Add limit switches for homing
- Implement variable speed control in UI
- Add timelapse mode (photo + rotation over hours)
- Support for photogrammetry exports

## Support Files

- Firmware: `/home/yourusername/Documents/scripts/esp32_turntable.ino`
- Flask API: `/home/yourusername/Documents/app.py`
- UI Snippet: `/home/yourusername/Documents/turntable_ui_snippet.html`
- This guide: `/home/yourusername/Documents/TURNTABLE_SETUP.md`

Happy shooting! 📷🔄

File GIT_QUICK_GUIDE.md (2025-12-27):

# Git Quick Reference for Manège

Simple commands for updating your GitHub repository.

## Every Time You Make Changes

### 1. Check what changed
```bash
cd /home/yourusername/manege
git status
```

### 2. See exactly what changed
```bash
git diff
```

### 3. Add all changes
```bash
git add .
```

### 4. Commit with a message
```bash
git commit -m "Brief description of what you changed"
```

### 5. Push to GitHub
```bash
git push
```

---

## Common Workflows

### After a coding session with Claude:
```bash
cd /home/yourusername/manege
git add .
git commit -m "Add focus stacking feature"
git push
```

### After fixing a bug:
```bash
git add .
git commit -m "Fix turntable homing issue"
git push
```

### After updating documentation:
```bash
git add .
git commit -m "Update README with new features"
git push
```

---

## Viewing History

### See recent commits
```bash
git log --oneline
```

### See what changed in last commit
```bash
git show
```

---

## Going Back in Time

### Undo changes before commit (careful!)
```bash
git checkout -- filename.py
```

### See old version without changing anything
```bash
git log --oneline           # Find commit hash
git show abc123:app/app.py  # View old version
```

---

## Working with Claude Code

When Claude Code helps you:

1. Make changes to your code
2. When done with session:
   ```bash
   git add .
   git commit -m "Session YYYY-MM-DD: [what we did]"
   git push
   ```

Example commit messages:
- "Session 2025-12-27: Add HDR capture mode"
- "Session 2025-12-28: Fix ESP32 WiFi reconnection"
- "Session 2025-12-29: Improve focus stacking algorithm"

---

## Safety Rules ⚠️

✅ **DO:**
- Commit often (every significant change)
- Write clear commit messages
- Push to GitHub regularly

❌ **DON'T:**
- Commit config.py or config.h (git will ignore them automatically)
- Commit photos or large files
- Force push (--force) unless you know what you're doing

---

## Check Repository Status Anytime

**On web:** https://github.com/fitaine/manege

**On Pi:**
```bash
cd /home/yourusername/manege
git status
git log --oneline -5  # Last 5 commits
```

---

## Troubleshooting

### "Nothing to commit"
Good! No changes since last commit.

### "Your branch is ahead"
You have local commits not pushed yet. Run: `git push`

### "Conflict" when pushing
Someone else changed the same file. Contact Claude for help!

### Forgot to commit before making more changes
No problem! Just commit now with all changes together.

---

**Remember:** Git is your friend! It's hard to lose work with git. When in doubt, ask Claude! 😊

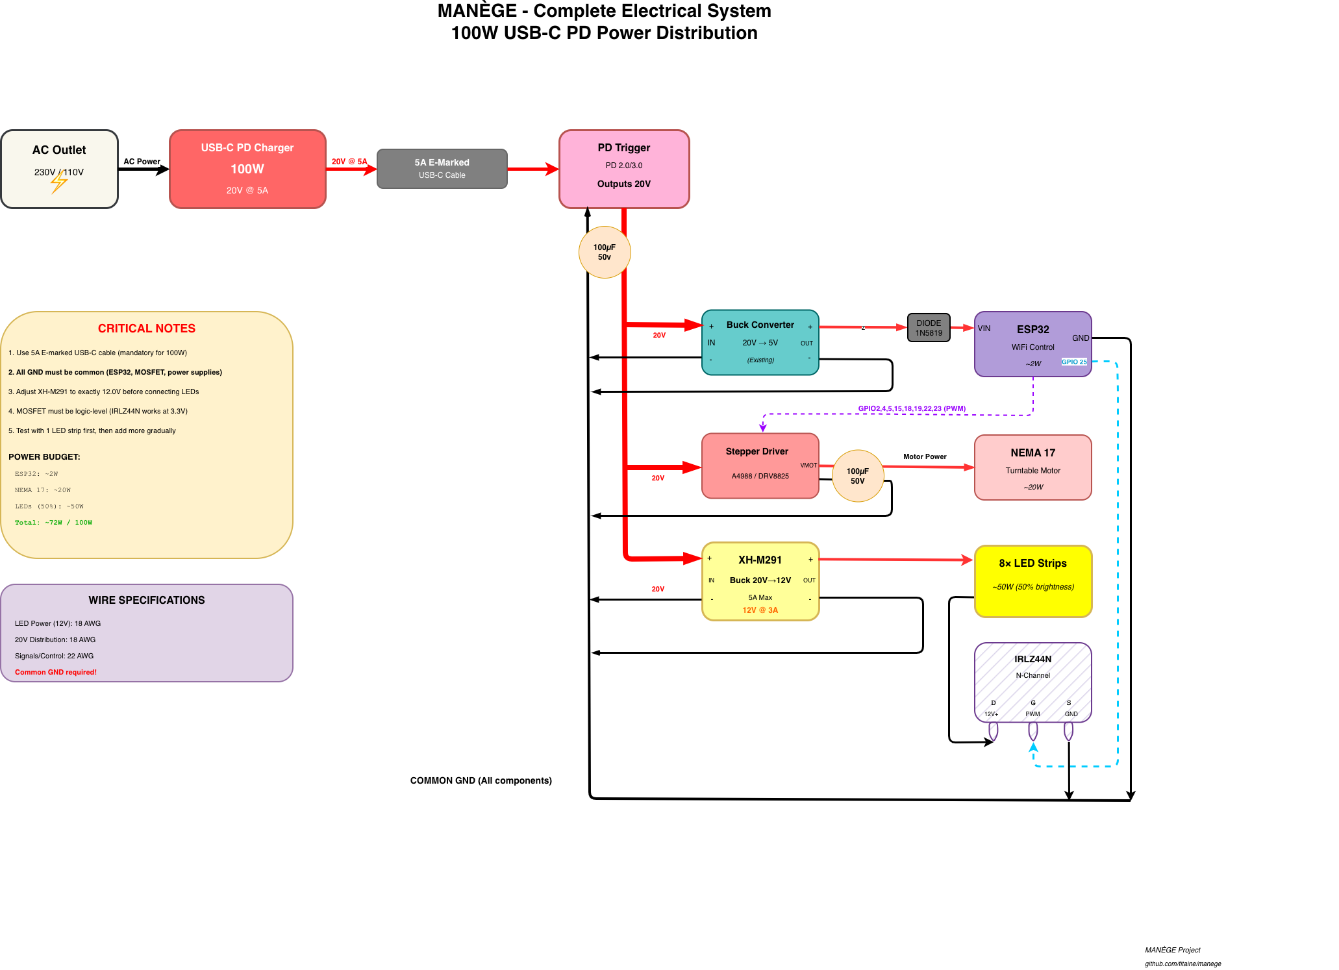
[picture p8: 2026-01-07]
hardware/electrical/Manege Wiring Diagram.png

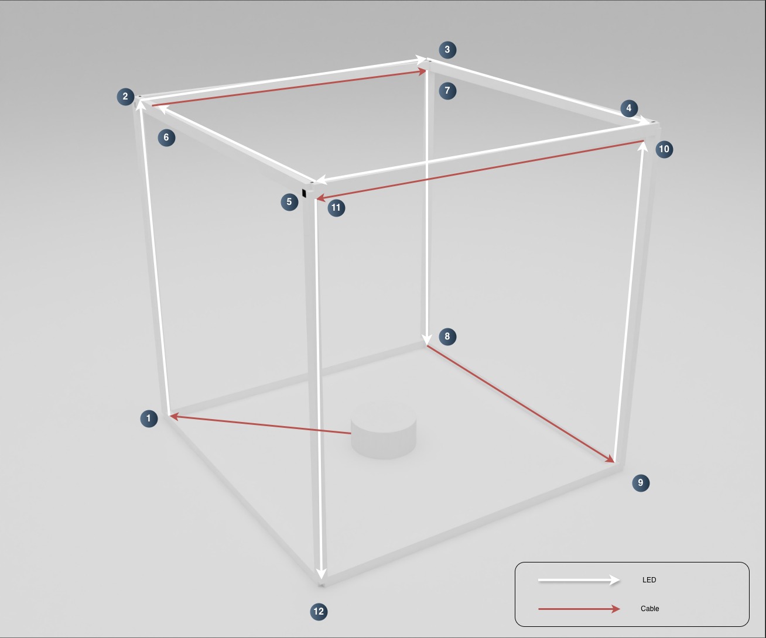
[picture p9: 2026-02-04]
hardware/electrical/LED wiring diagram.jpg

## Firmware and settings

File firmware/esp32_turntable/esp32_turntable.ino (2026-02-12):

// Manège Turntable Control - ESP32 + DRV8825 + AccelStepper
// Enhanced version with 360° photo sequence, video support, and LED control
// Based on working test code with improvements

#include <WiFi.h>
#include <WebServer.h>
#include <AccelStepper.h>
#include <ArduinoJson.h>

// Configuration (WiFi credentials, network settings)
#include "config.h"

// === Wi-Fi Configuration ===
// WiFi credentials moved to config.h
const char* ssid = WIFI_SSID;
const char* password = WIFI_PASSWORD;

// === Stepper Pin Assignments ===
#define STEP_PIN 5
#define DIR_PIN 2
#define SLP_PIN 18
#define RST_PIN 23
#define M0_PIN 4
#define M1_PIN 22
#define M2_PIN 19
#define EN_PIN 15

// === LED Control Pin ===
#define LED_PIN 25            // GPIO 25 for LED PWM control (MOSFET gate)
#define LED_PWM_CHANNEL 0     // PWM channel (0-15 available)
#define LED_PWM_FREQ 5000     // 5 kHz PWM frequency
#define LED_PWM_RESOLUTION 8  // 8-bit resolution (0-255)

// === Motor Configuration ===
const int STEPS_PER_REV = 200;       // 200 steps for full step mode (motor shaft)
const int MICROSTEPS = 32;           // 1/32 microstepping (M0=M1=M2=HIGH) for smooth motion
const int GEAR_RATIO = 10;           // 160 teeth ring gear / 16 teeth pinion = 10:1 reduction
const long TOTAL_STEPS = (long)STEPS_PER_REV * MICROSTEPS * GEAR_RATIO;  // 64000 steps per lazy susan revolution

// === Speed Profiles (adjusted for 1/32 microstepping + 5:1 gear ratio) ===
// Note: With 32x microstepping and 5x gear ratio, we have 160x more steps than direct full-step drive
// Speeds are in steps/second for the motor (not lazy susan rotation speed)
const int SPEED_SLOW = 800;          // For photo capture (very smooth, no vibration)
const int SPEED_MEDIUM = 1200;       // General positioning (gentle)
const int SPEED_FAST = 1600;         // Return home (smooth but faster)
const int SPEED_VIDEO = 400;         // Slow for 360° video (ultra smooth)

// === Gentle Accelerations (safe for delicate objects like basketery) ===
const int ACCEL_SLOW = 300;          // Very gentle start/stop
const int ACCEL_MEDIUM = 400;        // Gentle acceleration
const int ACCEL_FAST = 500;          // Return home acceleration (still gentle)

// === State Variables ===
AccelStepper stepper(AccelStepper::DRIVER, STEP_PIN, DIR_PIN);
WebServer server(80);

volatile bool isMoving = false;
volatile bool stopRequested = false;
long homePosition = 0;               // Reference home position
int currentLedBrightness = 0;        // Current LED brightness (0-255)

// === LED Control Functions ===
void setupLED() {
  ledcSetup(LED_PWM_CHANNEL, LED_PWM_FREQ, LED_PWM_RESOLUTION);
  ledcAttachPin(LED_PIN, LED_PWM_CHANNEL);
  ledcWrite(LED_PWM_CHANNEL, 0);  // Start with LEDs off
  Serial.println("LED PWM initialized on GPIO 25");
}

void setLedBrightness(int brightness) {
  // Constrain to 0-255
  brightness = constrain(brightness, 0, 255);
  currentLedBrightness = brightness;
  ledcWrite(LED_PWM_CHANNEL, brightness);
  
  Serial.print("LED brightness set to: ");
  Serial.print(brightness);
  Serial.print(" (");
  Serial.print((brightness * 100) / 255);
  Serial.println("%)");
}

void ledOn(int brightness = 255) {
  setLedBrightness(brightness);
}

void ledOff() {
  setLedBrightness(0);
}

// === Driver Control Functions ===
void wakeDriver() {
  digitalWrite(RST_PIN, HIGH);
  digitalWrite(SLP_PIN, HIGH);
  digitalWrite(EN_PIN, LOW);  // ENABLE LOW = enabled
}

void sleepDriver() {
  digitalWrite(SLP_PIN, LOW);
  digitalWrite(EN_PIN, HIGH); // ENABLE HIGH = disabled
}

// === Setup ===
void setup() {
  Serial.begin(115200);
  delay(1000);

  // Set motor control pins
  pinMode(SLP_PIN, OUTPUT);
  pinMode(RST_PIN, OUTPUT);
  pinMode(EN_PIN, OUTPUT);
  pinMode(M0_PIN, OUTPUT);
  pinMode(M1_PIN, OUTPUT);
  pinMode(M2_PIN, OUTPUT);

  // Set microstepping to 1/32 (M0=M1=M2=HIGH for DRV8825)
  digitalWrite(M0_PIN, HIGH);
  digitalWrite(M1_PIN, HIGH);
  digitalWrite(M2_PIN, HIGH);

  wakeDriver();
  delay(10);

  // Setup LED PWM
  setupLED();

  // Setup stepper motion parameters
  stepper.setMaxSpeed(SPEED_MEDIUM);
  stepper.setAcceleration(ACCEL_MEDIUM);

  // Connect to Wi-Fi with static IP
  IPAddress local_IP(192, 168, 1, 42);
  IPAddress gateway(192, 168, 1, 1);
  IPAddress subnet(255, 255, 255, 0);

  WiFi.config(local_IP, gateway, subnet);
  WiFi.begin(ssid, password);

  Serial.print("Connecting to WiFi");
  while (WiFi.status() != WL_CONNECTED) {
    delay(500);
    Serial.print(".");
  }
  Serial.println("\nWiFi connected!");
  Serial.print("IP: ");
  Serial.println(WiFi.localIP());

  // === HTTP API Routes ===
  setupRoutes();

  server.begin();
  Serial.println("HTTP server started");
  Serial.println("Manège Turntable Ready!");
}

void setupRoutes() {
  // Root endpoint - API documentation
  server.on("/", HTTP_GET, []() {
    String html = "<html><head><title>Manège Turntable</title></head><body>";
    html += "<h1>Manège Turntable Control</h1>";
    html += "<h2>Available Endpoints:</h2>";
    html += "<h3>Turntable Control:</h3>";
    html += "<ul>";
    html += "<li><b>GET /status</b> - Get current position and state</li>";
    html += "<li><b>POST /rotate?steps=N</b> - Rotate by N steps (+ = CW, - = CCW)</li>";
    html += "<li><b>POST /rotate_degrees?degrees=N</b> - Rotate by N degrees</li>";
    html += "<li><b>POST /goto?position=N</b> - Go to absolute position (0-360°)</li>";
    html += "<li><b>POST /home</b> - Return to home position (0°)</li>";
    html += "<li><b>POST /set_home</b> - Set current position as home</li>";
    html += "<li><b>POST /left?degrees=N</b> - Rotate left (CCW)</li>";
    html += "<li><b>POST /right?degrees=N</b> - Rotate right (CW)</li>";
    html += "<li><b>POST /photo360?count=N</b> - Prepare for N-photo 360° sequence</li>";
    html += "<li><b>POST /video360?duration=N</b> - Rotate 360° over N seconds</li>";
    html += "<li><b>POST /stop</b> - Emergency stop</li>";
    html += "<li><b>POST /sleep</b> - Disable motor (save power)</li>";
    html += "<li><b>POST /wake</b> - Enable motor</li>";
    html += "</ul>";
    html += "<h3>LED Control:</h3>";
    html += "<ul>";
    html += "<li><b>GET /led/status</b> - Get LED status</li>";
    html += "<li><b>POST /led?brightness=N</b> - Set brightness (0-255 or 0-100%)</li>";
    html += "<li><b>POST /led/on</b> - Turn LEDs on (full brightness)</li>";
    html += "<li><b>POST /led/off</b> - Turn LEDs off</li>";
    html += "<li><b>POST /led/brightness?value=N</b> - Set brightness (0-255)</li>";
    html += "<li><b>POST /led/percent?value=N</b> - Set brightness (0-100%)</li>";
    html += "</ul></body></html>";
    server.send(200, "text/html", html);
  });

  // Status endpoint - returns JSON
  server.on("/status", HTTP_GET, handleStatus);

  // Basic rotation
  server.on("/rotate", HTTP_POST, handleRotate);
  server.on("/rotate_degrees", HTTP_POST, handleRotateDegrees);

  // Absolute positioning
  server.on("/goto", HTTP_POST, handleGoto);
  server.on("/home", HTTP_POST, handleHome);
  server.on("/set_home", HTTP_POST, handleSetHome);

  // Simple left/right
  server.on("/left", HTTP_POST, handleLeft);
  server.on("/right", HTTP_POST, handleRight);

  // 360° capture modes
  server.on("/photo360", HTTP_POST, handlePhoto360);
  server.on("/video360", HTTP_POST, handleVideo360);
  server.on("/video360_loop", HTTP_POST, handleVideo360Loop);

  // Motor control
  server.on("/stop", HTTP_POST, handleStop);
  server.on("/sleep", HTTP_POST, handleSleep);
  server.on("/wake", HTTP_POST, handleWake);

  // LED control endpoints
  server.on("/led/status", HTTP_GET, handleLedStatus);
  server.on("/led", HTTP_POST, handleLed);
  server.on("/led/on", HTTP_POST, handleLedOn);
  server.on("/led/off", HTTP_POST, handleLedOff);
  server.on("/led/brightness", HTTP_POST, handleLedBrightness);
  server.on("/led/percent", HTTP_POST, handleLedPercent);

  // Legacy presets (keep for compatibility)
  server.on("/preset/45", HTTP_ANY, []() {
    rotateByDegrees(45, SPEED_MEDIUM, ACCEL_MEDIUM);
    sendJSON(200, "success", "Rotated 45 degrees");
  });

  server.on("/preset/360", HTTP_ANY, []() {
    rotateByDegrees(360, SPEED_MEDIUM, ACCEL_MEDIUM);
    sendJSON(200, "success", "Rotated 360 degrees");
  });
}

// === API Handlers ===

void handleStatus() {
  StaticJsonDocument<256> doc;
  doc["position_steps"] = stepper.currentPosition();
  doc["position_degrees"] = stepsToDegrees(stepper.currentPosition());
  doc["is_moving"] = isMoving;
  doc["distance_to_go"] = stepper.distanceToGo();
  doc["speed"] = stepper.speed();
  doc["max_speed"] = stepper.maxSpeed();
  doc["led_brightness"] = currentLedBrightness;
  doc["led_percent"] = (currentLedBrightness * 100) / 255;
  doc["wifi_rssi"] = WiFi.RSSI();

  String json;
  serializeJson(doc, json);
  server.send(200, "application/json", json);
}

void handleRotate() {
  if (!server.hasArg("steps")) {
    sendJSON(400, "error", "Missing 'steps' parameter");
    return;
  }

  int steps = server.arg("steps").toInt();
  Serial.print("Rotate: ");
  Serial.print(steps);
  Serial.println(" steps");

  rotateBySteps(steps, SPEED_MEDIUM, ACCEL_MEDIUM);
  sendJSON(200, "success", "Moved " + String(steps) + " steps");
}

void handleRotateDegrees() {
  if (!server.hasArg("degrees")) {
    sendJSON(400, "error", "Missing 'degrees' parameter");
    return;
  }

  float degrees = server.arg("degrees").toFloat();
  Serial.print("Rotate: ");
  Serial.print(degrees);
  Serial.println(" degrees");

  rotateByDegrees(degrees, SPEED_MEDIUM, ACCEL_MEDIUM);
  sendJSON(200, "success", "Rotated " + String(degrees) + " degrees");
}

void handleGoto() {
  if (!server.hasArg("position")) {
    sendJSON(400, "error", "Missing 'position' parameter");
    return;
  }

  float targetDegrees = server.arg("position").toFloat();
  gotoAbsolutePosition(targetDegrees);
  sendJSON(200, "success", "Moved to " + String(targetDegrees) + " degrees");
}

void handleHome() {
  Serial.println("Returning to home position");

  // Calculate shortest path to home
  long currentPos = stepper.currentPosition();
  long delta = homePosition - currentPos;

  // Normalize delta to find shortest rotation
  // If delta > half revolution, go the other way
  if (delta > TOTAL_STEPS / 2) {
    delta -= TOTAL_STEPS;
  } else if (delta < -TOTAL_STEPS / 2) {
    delta += TOTAL_STEPS;
  }

  // Move by the shortest delta
  long targetPos = currentPos + delta;

  Serial.print("Current: ");
  Serial.print(currentPos);
  Serial.print(", Home: ");
  Serial.print(homePosition);
  Serial.print(", Shortest delta: ");
  Serial.println(delta);

  stepper.moveTo(targetPos);
  stepper.setMaxSpeed(SPEED_MEDIUM);    // Slower, safer return home
  stepper.setAcceleration(ACCEL_MEDIUM); // Gentle acceleration
  runToTarget();

  // Sync position to home after arrival
  stepper.setCurrentPosition(homePosition);

  sendJSON(200, "success", "Returned to home");
}

void handleSetHome() {
  homePosition = stepper.currentPosition();
  Serial.print("Home position set to: ");
  Serial.println(homePosition);
  sendJSON(200, "success", "Home position set");
}

void handleLeft() {
  float degrees = server.hasArg("degrees") ? server.arg("degrees").toFloat() : 90;
  rotateByDegrees(-degrees, SPEED_MEDIUM, ACCEL_MEDIUM);
  sendJSON(200, "success", "Rotated left " + String(degrees) + " degrees");
}

void handleRight() {
  float degrees = server.hasArg("degrees") ? server.arg("degrees").toFloat() : 90;
  rotateByDegrees(degrees, SPEED_MEDIUM, ACCEL_MEDIUM);
  sendJSON(200, "success", "Rotated right " + String(degrees) + " degrees");
}

void handlePhoto360() {
  if (!server.hasArg("count")) {
    sendJSON(400, "error", "Missing 'count' parameter");
    return;
  }

  int photoCount = server.arg("count").toInt();

  if (photoCount < 1 || photoCount > 360) {
    sendJSON(400, "error", "Invalid count (1-360)");
    return;
  }

  Serial.print("Photo360 sequence: ");
  Serial.print(photoCount);
  Serial.println(" photos");

  float degreesPerPhoto = 360.0 / photoCount;

  // Return immediately - Pi will call /rotate_degrees for each step
  StaticJsonDocument<128> doc;
  doc["status"] = "ready";
  doc["photo_count"] = photoCount;
  doc["degrees_per_photo"] = degreesPerPhoto;
  doc["total_steps"] = photoCount;

  String json;
  serializeJson(doc, json);
  server.send(200, "application/json", json);
}

void handleVideo360() {
  if (!server.hasArg("duration")) {
    sendJSON(400, "error", "Missing 'duration' parameter");
    return;
  }

  int duration = server.arg("duration").toInt();  // Duration in seconds

  if (duration < 5 || duration > 300) {
    sendJSON(400, "error", "Invalid duration (5-300 seconds)");
    return;
  }

  Serial.print("Video360: ");
  Serial.print(duration);
  Serial.println(" seconds");

  // Calculate speed for smooth rotation over duration
  // speed = steps / time = TOTAL_STEPS / duration (steps per second)
  float speed = (float)TOTAL_STEPS / (float)duration;

  // Calculate acceleration proportional to speed for smooth ramp-up
  // Use 10% of duration for acceleration (reaches full speed quickly but smoothly)
  // accel = speed / (duration * 0.1)
  float accel = speed / (duration * 0.1);

  // Ensure minimum acceleration for very long videos
  if (accel < 50) accel = 50;

  stepper.setMaxSpeed(speed);
  stepper.setAcceleration(accel);

  long startPosition = stepper.currentPosition();
  stepper.moveTo(startPosition + TOTAL_STEPS);

  // Non-blocking - return immediately
  isMoving = true;

  StaticJsonDocument<128> doc;
  doc["status"] = "rotating";
  doc["duration"] = duration;
  doc["speed"] = speed;
  doc["total_steps"] = TOTAL_STEPS;

  String json;
  serializeJson(doc, json);
  server.send(200, "application/json", json);
}

void handleVideo360Loop() {
  if (!server.hasArg("duration")) {
    sendJSON(400, "error", "Missing 'duration' parameter");
    return;
  }

  int duration = server.arg("duration").toInt();  // Duration in seconds

  if (duration < 5 || duration > 300) {
    sendJSON(400, "error", "Invalid duration (5-300 seconds)");
    return;
  }

  Serial.print("Video360 Loop mode: ");
  Serial.print(duration);
  Serial.println(" seconds");

  // Calculate speed and acceleration for the specified duration
  float speed = (float)TOTAL_STEPS / (float)duration;
  float accel = speed / (duration * 0.1);
  if (accel < 50) accel = 50;

  // Calculate steps during acceleration phase (10% of total rotation)
  long accelSteps = TOTAL_STEPS / 10;  // 10% of 360° = 36°

  stepper.setMaxSpeed(speed);
  stepper.setAcceleration(accel);

  long startPos = stepper.currentPosition();

  // Phase 1: Pre-position backwards by 10% (move to -36° from start)
  // This is done at medium speed with normal acceleration
  stepper.setMaxSpeed(SPEED_MEDIUM);
  stepper.setAcceleration(ACCEL_MEDIUM);
  stepper.moveTo(startPos - accelSteps);
  isMoving = true;
  runToTarget();

  // Phase 2: Accelerate forward through the 36° back to start position
  // By the time we reach startPos, we'll be at full cruise speed
  // Then continue for full 360° rotation plus deceleration distance
  stepper.setMaxSpeed(speed);
  stepper.setAcceleration(accel);
  stepper.moveTo(startPos + TOTAL_STEPS + accelSteps);  // 360° + 36° for deceleration
  isMoving = true;

  // Note: This is non-blocking. The sequence will be:
  // 1. Currently at: startPos - 36° (pre-positioned)
  // 2. Accelerate to startPos (cruise speed reached) <- Recording starts here
  // 3. Cruise for 360° at constant speed <- Recording happens during this
  // 4. Decelerate for final 36° <- Recording stops before this
  // 5. (Phase 3 below) Return to startPos

  // Return immediately - rotation is non-blocking
  StaticJsonDocument<128> doc;
  doc["status"] = "rotating_loop";
  doc["duration"] = duration;
  doc["speed"] = speed;
  doc["accel_steps"] = accelSteps;
  doc["start_position"] = startPos;

  String json;
  serializeJson(doc, json);
  server.send(200, "application/json", json);
}

void handleStop() {
  Serial.println("Emergency stop!");
  stepper.stop();
  stopRequested = true;
  isMoving = false;
  sendJSON(200, "success", "Motor stopped");
}

void handleSleep() {
  sleepDriver();
  sendJSON(200, "success", "Motor disabled (sleeping)");
}

void handleWake() {
  wakeDriver();
  sendJSON(200, "success", "Motor enabled");
}

// === LED Control Handlers ===

void handleLedStatus() {
  StaticJsonDocument<128> doc;
  doc["brightness"] = currentLedBrightness;
  doc["percent"] = (currentLedBrightness * 100) / 255;
  doc["is_on"] = currentLedBrightness > 0;

  String json;
  serializeJson(doc, json);
  server.send(200, "application/json", json);
}

void handleLed() {
  if (!server.hasArg("brightness")) {
    sendJSON(400, "error", "Missing 'brightness' parameter");
    return;
  }

  int brightness = server.arg("brightness").toInt();
  
  // Auto-detect if value is percentage (0-100) or raw (0-255)
  if (brightness <= 100) {
    // Assume percentage
    brightness = map(brightness, 0, 100, 0, 255);
  }
  
  setLedBrightness(brightness);
  sendJSON(200, "success", "LED brightness set to " + String(currentLedBrightness));
}

void handleLedOn() {
  int brightness = 255;
  if (server.hasArg("brightness")) {
    brightness = server.arg("brightness").toInt();
    if (brightness <= 100) {
      brightness = map(brightness, 0, 100, 0, 255);
    }
  }
  
  ledOn(brightness);
  sendJSON(200, "success", "LEDs turned on");
}

void handleLedOff() {
  ledOff();
  sendJSON(200, "success", "LEDs turned off");
}

void handleLedBrightness() {
  if (!server.hasArg("value")) {
    sendJSON(400, "error", "Missing 'value' parameter");
    return;
  }

  int brightness = server.arg("value").toInt();
  brightness = constrain(brightness, 0, 255);
  
  setLedBrightness(brightness);
  sendJSON(200, "success", "LED brightness set to " + String(brightness));
}

void handleLedPercent() {
  if (!server.hasArg("value")) {
    sendJSON(400, "error", "Missing 'value' parameter");
    return;
  }

  int percent = server.arg("value").toInt();
  percent = constrain(percent, 0, 100);
  int brightness = map(percent, 0, 100, 0, 255);
  
  setLedBrightness(brightness);
  sendJSON(200, "success", "LED brightness set to " + String(percent) + "%");
}

// === Helper Functions ===

void rotateBySteps(int steps, int speed, int accel) {
  stepper.setMaxSpeed(speed);
  stepper.setAcceleration(accel);
  stepper.moveTo(stepper.currentPosition() + steps);
  runToTarget();
}

void rotateByDegrees(float degrees, int speed, int accel) {
  int steps = degreesToSteps(degrees);
  rotateBySteps(steps, speed, accel);
}

void gotoAbsolutePosition(float targetDegrees) {
  // Normalize to 0-360
  while (targetDegrees < 0) targetDegrees += 360;
  while (targetDegrees >= 360) targetDegrees -= 360;

  long targetSteps = homePosition + degreesToSteps(targetDegrees);
  long currentSteps = stepper.currentPosition();

  // Calculate shortest path
  long delta = targetSteps - currentSteps;
  long altDelta = delta > 0 ? delta - TOTAL_STEPS : delta + TOTAL_STEPS;

  if (abs(altDelta) < abs(delta)) {
    delta = altDelta;
  }

  rotateBySteps(delta, SPEED_FAST, ACCEL_FAST);
}

void runToTarget() {
  isMoving = true;
  stopRequested = false;

  Serial.println("Starting movement...");
  Serial.print("Target: ");
  Serial.println(stepper.targetPosition());

  while (stepper.distanceToGo() != 0 && !stopRequested) {
    stepper.run();
    server.handleClient();  // Keep server responsive during movement
  }

  isMoving = false;
  Serial.println("Movement complete");
}

int degreesToSteps(float degrees) {
  return (int)((degrees / 360.0) * TOTAL_STEPS);
}

float stepsToDegrees(long steps) {
  return (steps % TOTAL_STEPS) * (360.0 / TOTAL_STEPS);
}

void sendJSON(int code, String status, String message) {
  StaticJsonDocument<128> doc;
  doc["status"] = status;
  doc["message"] = message;

  String json;
  serializeJson(doc, json);
  server.send(code, "application/json", json);
}

// === Main Loop ===
void loop() {
  server.handleClient();

  // Continue running stepper if in non-blocking mode (e.g., video360)
  if (isMoving && stepper.distanceToGo() != 0) {
    stepper.run();
  } else if (isMoving && stepper.distanceToGo() == 0) {
    isMoving = false;
    Serial.println("Non-blocking movement complete");
  }

  // Optional: Auto-sleep after 60 seconds of inactivity
  static unsigned long lastMoveTime = 0;
  if (stepper.distanceToGo() != 0) {
    lastMoveTime = millis();
  }

  // Uncomment to enable auto-sleep:
  // if (millis() - lastMoveTime > 60000) {
  //   sleepDriver();
  //   lastMoveTime = millis();  // Reset timer
  // }
}

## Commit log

2025-12-27 Initial commit - Manège automated photobox
    Complete 360° photography system for artisans and craftspeople.
    Features:
    - Raspberry Pi camera with manual controls (focus, exposure, WB)
    - ESP32-controlled precision turntable (64,000 steps/360°)
    - Web-based interface for remote operation
    - 360° photo sequences and video recording
    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
2025-12-27 Add comprehensive camera setup documentation
    Explains why we use libcamera (not picamera) and how to set up Camera Module V3.
    Addresses common confusion between old and new camera systems.
2025-12-27 Add BOM and reorganize documentation
    - Add BOM.md: Complete parts list with prices and recommendations
    - Move CAMERA_SETUP.md from docs/ to app/ folder
    - Remove docs/ folder (not needed for now)
    - Update README with new camera doc location
2025-12-27 Update BOM with actual hardware specifications
    - Remove all prices (focus on parts, not cost)
    - Raspberry Pi 5 required for dual camera setup
    - Specify two cameras: Camera HQ (capture) + Module V3 (preview)
    - Add actual power components: XH-M291 (12V), LM2596 (5V)
    - Add 8 inch Lazy Susan
    - Note AliExpress as primary source
    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
2025-12-27 Update Raspberry Pi 5 RAM specification to 16GB
2025-12-27 Remove assembly order section from BOM.md
    Removed the detailed assembly order section from BOM.md.
2025-12-27 Add assembly order guide
    Step-by-step build sequence for Manège:
    - Electronics breadboard test
    - Raspberry Pi setup (dual cameras)
    - Mechanical assembly
    - Software setup
    - Final integration
    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
2025-12-27 Sanitize wiring guide - remove sensitive network information
    Replace actual credentials with placeholders:
    - WiFi SSID: YourWiFiName
    - WiFi Password: YourWiFiPassword
    - Pi IP: <PI_IP_ADDRESS>
    - ESP32 IP: <ESP32_IP_ADDRESS>
2025-12-27 Sanitize PHOTOBOX_TURNTABLE_README - remove network credentials
    Replace all sensitive network information with placeholders:
    - WiFi credentials
    - IP addresses (Pi and ESP32)
2025-12-27 SECURITY: Remove all sensitive information from repository
    Sanitized all files to remove:
    - WiFi password (lecodewifi)
    - Security code (070423)
    - Actual IP addresses (192.168.2.5, 192.168.1.42)
    - Username in paths (/home/florine → /home/yourusername)
    - Personal file paths
    Replaced with generic placeholders for user customization.
    Files sanitized:
    - app/app.py
    - All scripts (capture_photo.sh, run_photobox.sh, start_webapp.sh)
    - All hardware documentation
    - Git and camera guides
    All actual credentials remain protected in git-ignored config files.
2025-12-27 Add 3D printed corner brackets documentation and image
    - Add README.md for 3D printed parts
    - Document corner brackets for DIY photography lightbox
    - Link to Printables: https://www.printables.com/model/1341411
    - Add lightbox frame assembly image
    - Explain how brackets build cube frame for LED lightbox
    - Describe integration with Manège turntable system
    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
2025-12-27 Update README with new features
    Add features for led powering system and PoE Hat.
2025-12-27 Revamp README with compelling feature-focused presentation for makers
    Transform the README from a technical specification into an engaging marketing document that highlights Manège's complete feature set: dual camera system, PoE one-cable solution, integrated LED power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
2025-12-27 Add web app screenshot to README
    Include screenshot of the Manège web interface showing the intuitive control panel with live preview, manual camera settings (gain, speed, EV, WB, saturation, contrast), turntable rotation controls, 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
2025-12-27 Rebrand: Replace all 'photobox' references with 'Manège'
    Systematically replaced all instances of 'photobox' throughout the codebase to use the proper product name 'Manège' for consistent branding:
    - ASSEMBLY_ORDER.md: Updated product references
    - firmware/esp32_turntable.ino: Updated code comments and serial output
    - app/templates/index.html: Updated page title and header
    - hardware/mechanical/TURNTABLE_SETUP.md: Updated documentation
    - hardware/3d-printed/README.md: Updated component descriptions
    - hardware/electrical/wiring-guide.md: Updated integration references
    - BOM.md: Updated product description
    - Renamed: PHOTOBOX_TURNTABLE_README.md → MANEGE_TURNTABLE_README.md
    This cleanup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
    [esp32_turntable.ino]
2025-12-27 Modify camera module specifications in README
    Updated camera module requirements in the README.
2025-12-28 Added Manège Wiring Diagram.drawio
2025-12-28 Modified Manege Wiring Diagram.drawio
2025-12-28 Update Manege Wiring Diagram.drawio
2025-12-28 Update Manege Wiring Diagram.drawio with diode
2025-12-28 Added Manege Wiring Diagram.svg
2025-12-28 Added Manege Wiring Diagram.pdf
2025-12-28 Updated Manege Wiring Diagram.png
2025-12-28 Added Manege Wiring Diagram.png
2025-12-28 Added Manege PIN OUT close up.drawio
2025-12-28 Add LED PWM control and update wiring guide
    - Add GPIO 25 LED control with PWM brightness (0-255)
    - Add LED API endpoints: /led, /led/on, /led/off, /led/brightness
    - Update wiring guide with:
    - Diode protection for USB programming (1N5819)
    - Common ground bus bar implementation
    - Corrected LED low-side switching (MOSFET after LED strip)
    - 4 capacitor specifications with voltage ratings
    - NEMA motor ground clarification (no 5th wire)
    - Updated testing checklists
    [esp32_turntable.ino]
2025-12-28 Rewrite README with honest, humble tone
    - Tell the real story: built for a willow basket maker wife
    - Remove pretentious marketing language
    - Focus on practical use case and real benefits
    - Keep technical details but frame them honestly
    - "It ain't much but it's honest work"
2025-12-28 Add animated turntable rotation GIF
    - Replace static 3D render with looping animation
    - Shows turntable top plate rotating
    - Optimized 90-frame animation (600px, 12fps, 2.1MB)
    - Auto-loops infinitely in GitHub README
2026-01-02 Update gear design for easier 3D printing
    - Redesigned gears with larger module (1.15 → 1.25) for better printability
    - Changed gear ratio from 10:1 to 5:1 (110:22 teeth vs 160:16)
    - Optimized ring gear to fit 146.8mm lazy susan constraint
    - Updated firmware GEAR_RATIO constant to match new 5:1 reduction
    - Added OpenSCAD file with herringbone gear configuration
    - Pinion increased to 30mm diameter (easier to print, more robust)
    - Ring gear: 143.5mm OD with 3mm rim width
    [Manege_GEARS.scad]
2026-01-07 Update wiring guide with onboard capacitor info
    Reduced required external capacitors from 4 to 2:
    - LM2596 has built-in 100µF @ 50V caps (input + output)
    - XH-M291 has built-in 220µF @ 50V caps (C4 + C8)
    - Added PD Trigger output capacitor (100µF @ 50V)
    - Made LED strip capacitor optional (only if flicker)
    Simplified BOM and assembly checklist accordingly.
2026-01-07 modified the wiring diagram (deleted the unnecessary capacitors)
2026-01-07 deleted unnecessary capacitors
2026-01-07 Add part selector to gear file for individual exports
    Added 'part' parameter to allow exporting ring and pinion gears
    separately for 3D printing. Set to 'ring', 'pinion', or 'both'.
    Makes it easier to export individual STL files without manually
    commenting out parts.
    [Manege_GEARS.scad]
2026-01-24 Add dual-camera support (HQ + V3)
    - Add camera detection for IMX477 (HQ) and IMX708 (V3)
    - Add --camera flag to all rpicam commands
    - Add auto-switch: V3 provides preview while HQ records video
    - Add /api/cameras, /api/camera/switch, /api/camera/auto-switch endpoints
    - Add camera toggle switch UI (HQ/V3) with auto checkbox
    - Fix stream killed on page load by deferring exposure/focus updates
2026-01-25 Fix focus section: add wheel support and hide for HQ camera
    - Add mouse wheel handler for horizontal Focus carousel scrolling
    - Hide focus controls when HQ camera (16mm manual lens) is selected
    - Show focus controls when V3 camera is selected
    - Fix misplaced closing div tag in footer
2026-01-25 Fix scope issue: move updateFocusSectionVisibility to global scope
    The function was defined inside DOMContentLoaded but called from
    switchCamera and loadCameraState which are at global scope.
2026-01-25 Add focus carousel wheel support and hide for HQ camera
    - Mouse wheel scrolls focus distance carousel horizontally
    - Hide focus section when HQ camera (16mm manual lens) is selected
    - Show focus section when V3 camera is selected
2026-01-25 Fix light tab closing and hide focus section for HQ camera
    - Fixed light tab not closing by matching contrast section structure
    - Restored light bulb icon and On/Off toggle in light section
    - Hide focus section when HQ camera (manual lens) is selected
    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
2026-01-25 Fix HQ camera aspect ratio and improve UI layout
    - Set HQ camera stream to 1440x1080 (4:3) to match native sensor ratio
    - Set V3 camera stream to 1920x1080 (16:9)
    - Move camera info (ISO, Speed, WB, Tint) to header
    - Add refresh button for camera settings in header
    - Remove last modified section
    - Add lens switch overlay button on video feed (bottom-right)
    - New camera+arrows icon for lens switching
2026-01-26 Improve video container layout and lens switch button positioning
    - Restructure video container with proper flex layout for consistent display across both cameras
    - Fix lens switch overlay button to stay fully inside video bounds
    - Center footer tabs and section content
    - Align video to top while keeping horizontal centering
    - Add shadow to video wrapper for depth
2026-01-26 Update camera switch button icon and center UI elements
    - Replace switch camera icon with camera + circular arrows design
    - Remove camera name label from switch button
    - Center toggle switches in side panels
    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
2026-02-04 Added LED wiring diagram.jpg
2026-02-04 Added LED Wiring Diagram.drawio
2026-02-10 Fix turntable rotation failures and video recording errors
    ESP32 blocking endpoints drop HTTP connections before responding,
    causing 360° photo sequences to abort after the first photo. Added
    polling-based helpers (turntable_rotate_and_wait, turntable_home_and_wait)
    that send the command then poll /status until complete. Also installed
    ffmpeg and added turntable stop on video recording errors to prevent
    endless spinning.
2026-02-12 Fix gear ratio: 5:1 → 10:1 to match actual 160T/16T pulleys
    Rotation was 2x expected (45° command → 90° actual) because
    GEAR_RATIO was set to 5 (old 110T/22T) instead of 10 (actual 160T/16T).
    TOTAL_STEPS now correctly computes to 64000.
    [esp32_turntable.ino]
